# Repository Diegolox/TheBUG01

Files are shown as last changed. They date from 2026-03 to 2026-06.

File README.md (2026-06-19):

# TheBUG01 ⚡

## 🇬🇧 Project Description

<p align="justify">
This project is a custom <strong>all-in-one PCB</strong> for a <strong>two-wheel differential drive robot</strong>, designed to be <strong>plug-and-play</strong> and easy to integrate into new robotics prototypes. The board brings together the key building blocks needed for motion control and autonomous navigation, so you can focus on software and algorithms instead of wiring and power integration.
</p>

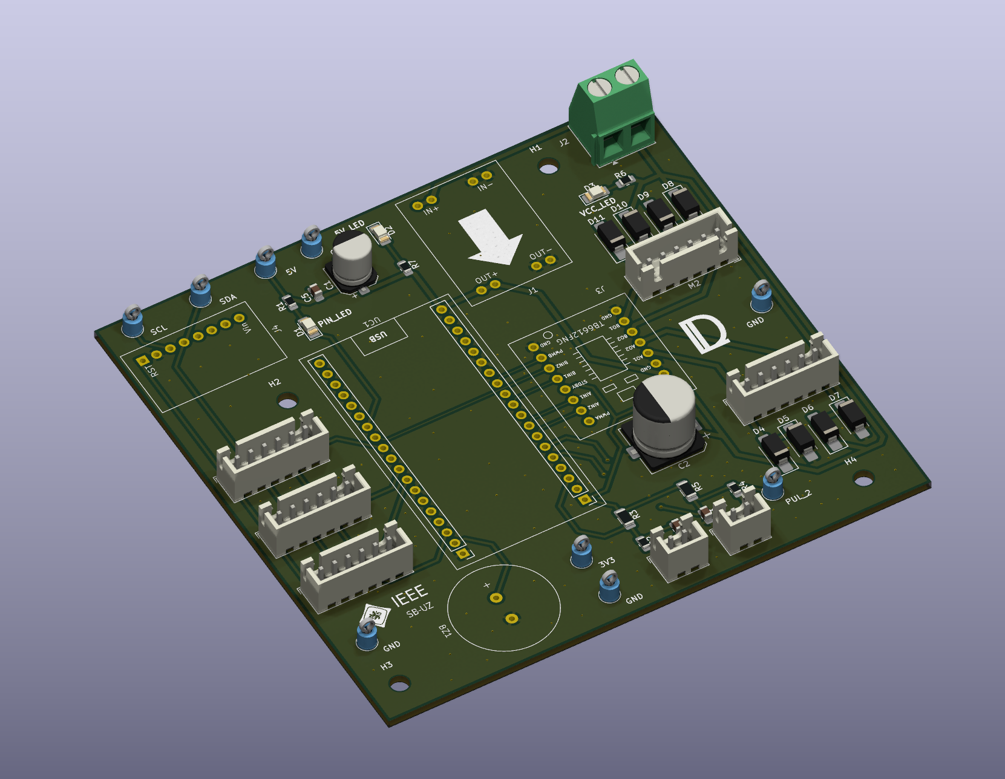
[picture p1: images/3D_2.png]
Vista 3D


### Key Features

* **2-wheel robot control PCB** with integrated peripherals for rapid development.
* **IMU (Inertial Measurement Unit)** for orientation and motion sensing.
* **3× TOF400 laser distance sensors** connected via **I²C**, enabling obstacle detection and basic autonomous navigation.
* **TB6612FNG dual motor driver** for controlling the DC motors efficiently (PWM + direction control).
* **Motor protection circuitry** to handle cases where motors behave like generators (back-EMF / regenerative effects), improving robustness and protecting the power stage.
* **Push buttons** with **RC filtering** and **external pull-up**, providing stable, noise-resistant digital inputs.
* **Test LEDs** for quick debugging and status indication during bring-up.
* **Integrated DC-DC converter** to step down from the **battery voltage** to the robot’s required internal rail(s), simplifying power distribution and improving overall reliability.

### PCB Layout
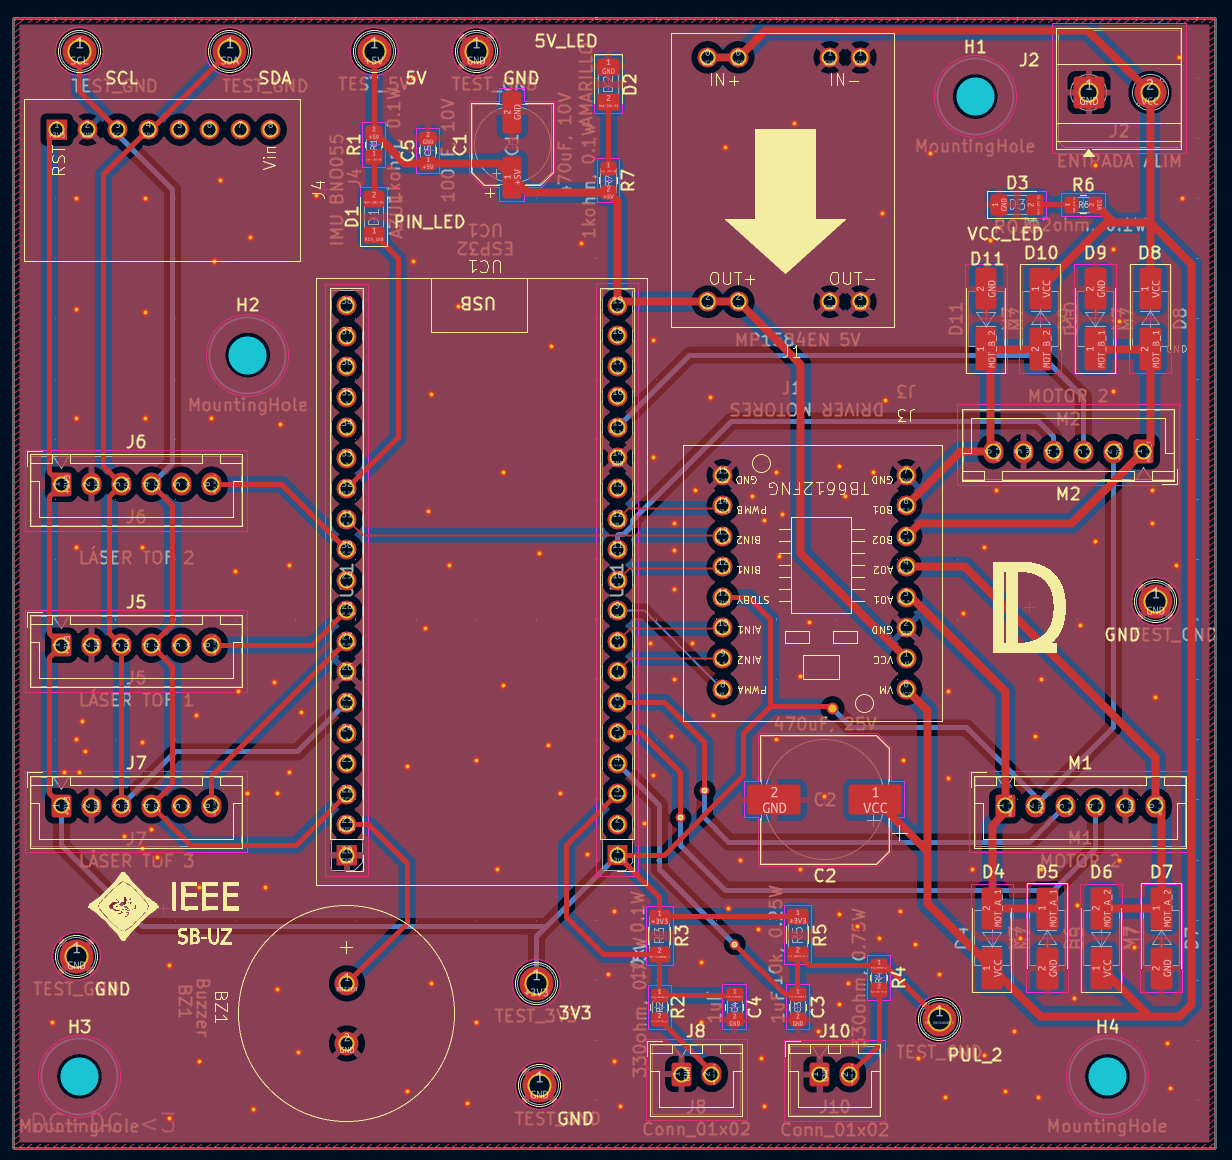
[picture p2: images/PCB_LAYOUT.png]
PCB Layout


### Schematic
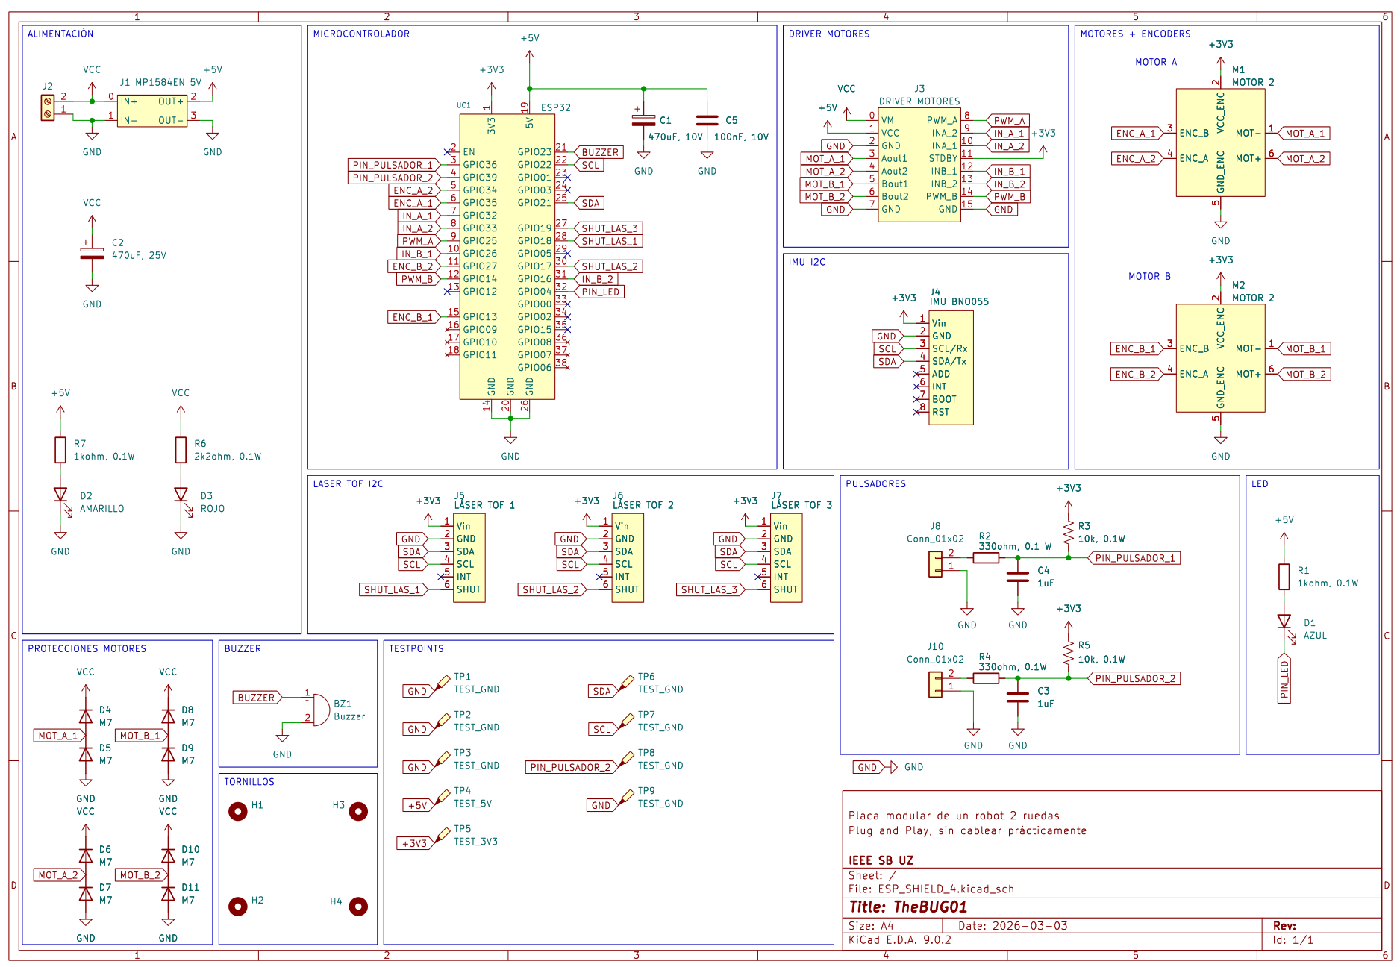
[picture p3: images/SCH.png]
Esquemático


### Goal

<p align="justify">
The goal of this PCB is to provide a compact robotics platform with <strong>everything integrated</strong>: power regulation, sensing, motor driving, and basic user I/O. With this hardware, you can quickly implement and iterate on:
</p>

* Wheel speed and position control loops
* Differential drive kinematics
* Sensor-based navigation using the TOF lasers
* Autonomous behaviors (obstacle avoidance, wall following, basic SLAM-ready sensing layout)

---

## 🇪🇸 Descripción del proyecto

<p align="justify">
Este proyecto es una <strong>PCB todo-en-uno</strong> para un <strong>robot diferencial de dos ruedas</strong>, pensada para ser <strong>plug-and-play</strong> y facilitar el desarrollo rápido de prototipos. La placa integra los bloques principales necesarios para control de movimiento y navegación autónoma, evitando cableado extra y problemas de integración de potencia.
</p>

### Características principales

* **PCB de control para robot de 2 ruedas** con periféricos integrados para desarrollo rápido.
* **IMU (Unidad de Medición Inercial)** para estimar orientación y movimiento.
* **3× sensores láser de distancia TOF400** por **I²C**, para detección de obstáculos y navegación básica.
* **Driver dual TB6612FNG** para el control eficiente de motores DC (PWM + dirección).
* **Circuitería de protección para motores** cuando actúan como generadores (back-EMF / regeneración), aumentando la robustez y protegiendo la etapa de potencia.
* **Pulsadores** con **filtro RC** y **pull-up externa**, para entradas digitales estables y resistentes al ruido.
* **LEDs de testeo** para depuración rápida y verificación del estado durante el bring-up.
* **Convertidor DC-DC integrado** para bajar la **tensión de baterías** a las líneas internas del robot, simplificando la distribución de potencia.

### Objetivo

<p align="justify">
El objetivo es ofrecer una plataforma compacta con <strong>todo integrado</strong>: regulación de potencia, sensórica, driver de motores y E/S básica. Con este hardware se pueden implementar de forma rápida:
</p>

* Control de velocidad/posición de ruedas
* Cinemática diferencial
* Navegación basada en sensores TOF
* Comportamientos autónomos (evitación de obstáculos, seguimiento de pared, base para SLAM)

---

* **Status:** In development
* **In collaboration with Carlos Rios Ferrer**

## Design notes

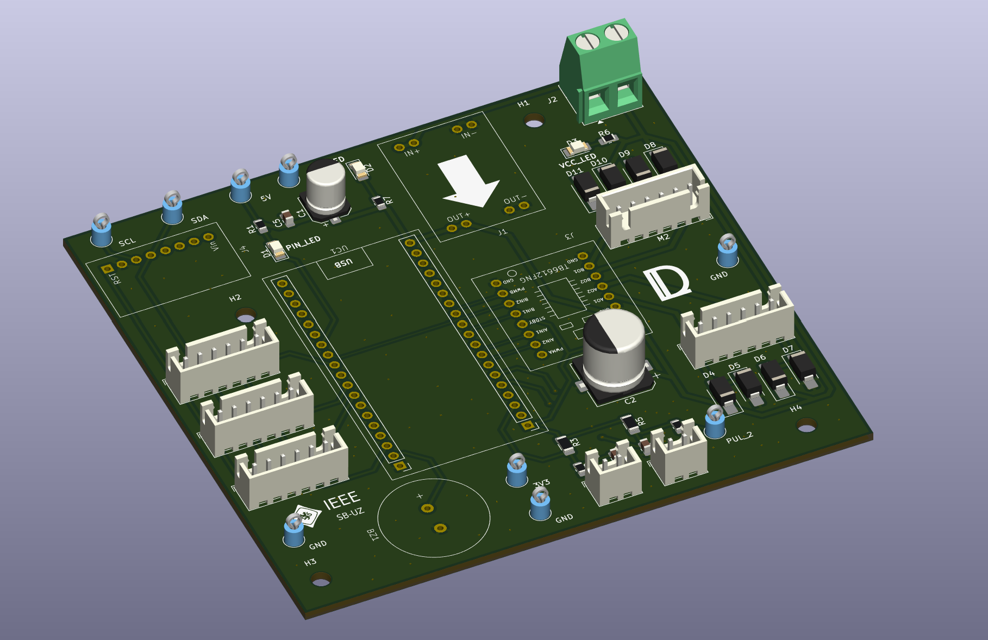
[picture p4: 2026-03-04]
images/3D.png

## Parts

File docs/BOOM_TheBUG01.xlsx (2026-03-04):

Reference | Qty | Value | DNP | Footprint
BZ1 | 1 | Buzzer |  | TOOLS_DIEGO:BUZZER
C1 | 1 | 470uF, 10V |  | Capacitor_SMD:CP_Elec_6.3x7.7
C2 | 1 | 470uF, 25V |  | Capacitor_SMD:CP_Elec_10x10.5
C3,C4 | 2 | 1uF |  | Capacitor_SMD:C_0805_2012Metric_Pad1.18x1.45mm_HandSolder
C5 | 1 | 100nF, 10V |  | Capacitor_SMD:C_0805_2012Metric_Pad1.18x1.45mm_HandSolder
D1 | 1 | AZUL |  | LED_SMD:LED_1206_3216Metric_Pad1.42x1.75mm_HandSolder
D2 | 1 | AMARILLO |  | LED_SMD:LED_1206_3216Metric_Pad1.42x1.75mm_HandSolder
D3 | 1 | ROJO |  | LED_SMD:LED_1206_3216Metric_Pad1.42x1.75mm_HandSolder
D4,D5,D6,D7,D8,D9,D10,D11 | 8 | M7 |  | Diode_SMD:D_SMA_Handsoldering
H1,H2,H3,H4 | 4 | MountingHole |  | MountingHole:MountingHole_3.2mm_M3
J1 | 1 | MP1584EN 5V |  | TOOLS_DIEGO:MP1584
J2 | 1 | ENTRADA ALIM |  | TerminalBlock_Phoenix:TerminalBlock_Phoenix_MKDS-1,5-2-5.08_1x02_P5.08mm_Horizontal
J3 | 1 | DRIVER MOTORES |  | TOOLS_DIEGO:TB6612FNG
J4 | 1 | IMU BNO055 |  | TOOLS_DIEGO:BNO055
J5 | 1 | LÃ SER TOF 1 |  | Connector_JST:JST_XH_B6B-XH-A_1x06_P2.50mm_Vertical
J6 | 1 | LÃ SER TOF 2 |  | Connector_JST:JST_XH_B6B-XH-A_1x06_P2.50mm_Vertical
J7 | 1 | LÃ SER TOF 3 |  | Connector_JST:JST_XH_B6B-XH-A_1x06_P2.50mm_Vertical
J8,J10 | 2 | Conn_01x02 |  | Connector_JST:JST_XH_B2B-XH-A_1x02_P2.50mm_Vertical
M1,M2 | 2 | MOTOR 2 |  | Connector_JST:JST_XH_B6B-XH-A_1x06_P2.50mm_Vertical
R1,R7 | 2 | 1kohm, 0.1W |  | Resistor_SMD:R_0805_2012Metric_Pad1.20x1.40mm_HandSolder
R2,R4 | 2 | 330ohm, 0.75W |  | Resistor_SMD:R_0805_2012Metric_Pad1.20x1.40mm_HandSolder
R3 | 1 | 10k, 0.1W |  | Resistor_SMD:R_1206_3216Metric_Pad1.30x1.75mm_HandSolder
R5 | 1 | 10k, 0.25W |  | Resistor_SMD:R_1206_3216Metric_Pad1.30x1.75mm_HandSolder
R6 | 1 | 2k2ohm, 0.1W |  | Resistor_SMD:R_0805_2012Metric_Pad1.20x1.40mm_HandSolder
TP1,TP2,TP3,TP6,TP7,TP8,TP9 | 7 | TEST_GND |  | TestPoint:TestPoint_Keystone_5005-5009_Compact
TP4 | 1 | TEST_5V |  | TestPoint:TestPoint_Keystone_5005-5009_Compact
TP5 | 1 | TEST_3V3 |  | TestPoint:TestPoint_Keystone_5005-5009_Compact
UC1 | 1 | ESP32 |  | ESP32_TOOLS_DIEGO:ESP32_WROOM32_SHIELD_V01

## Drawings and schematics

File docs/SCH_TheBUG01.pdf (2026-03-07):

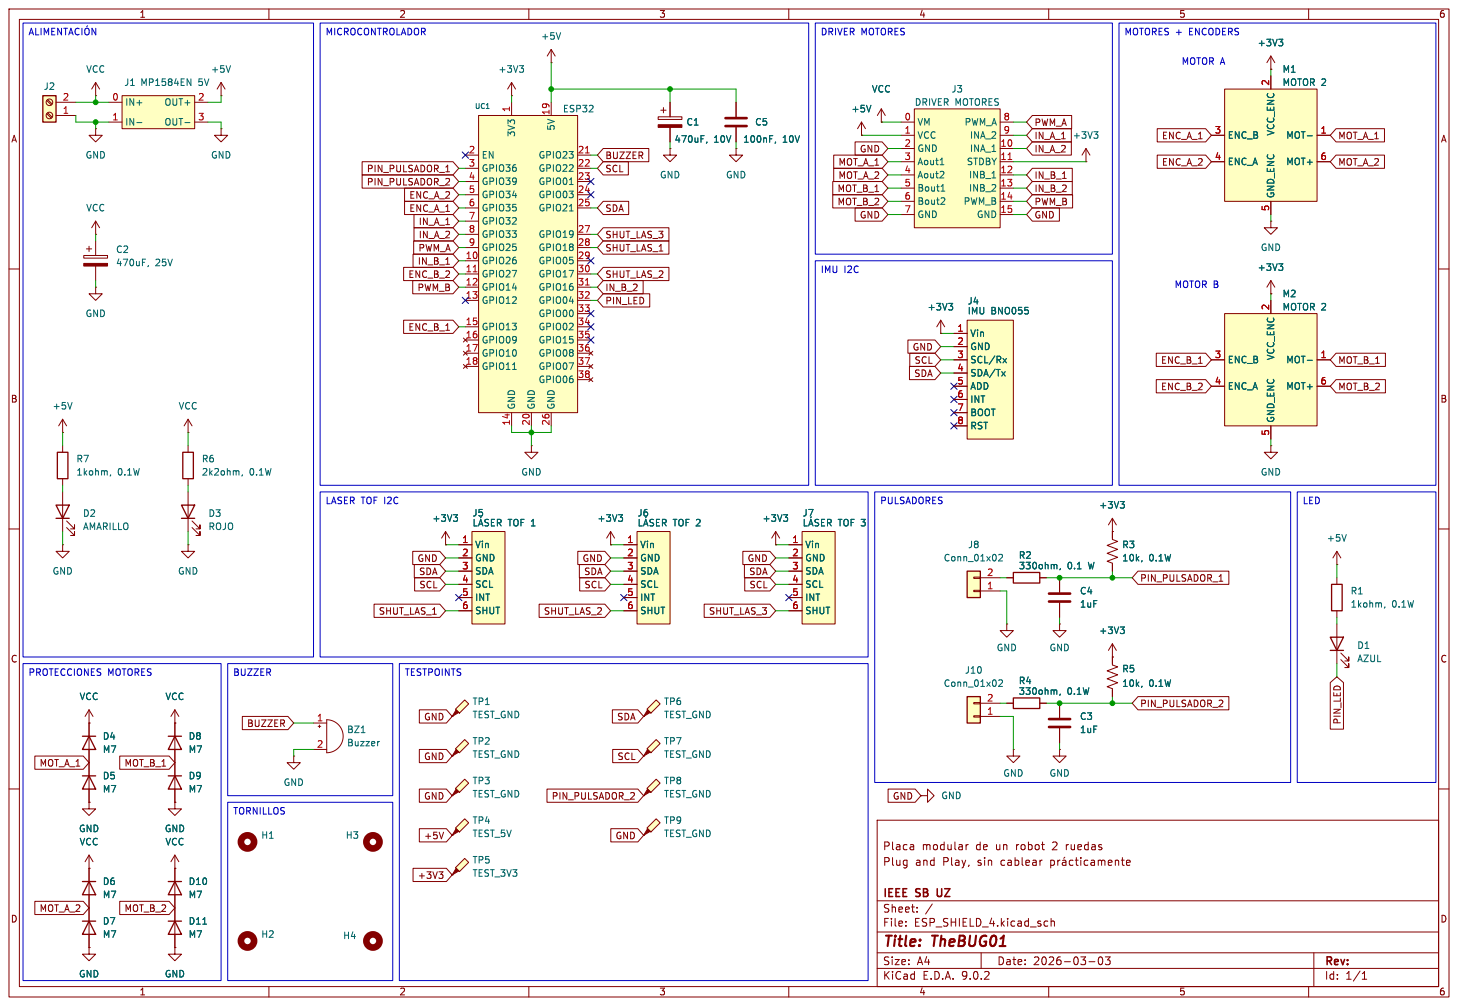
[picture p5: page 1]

5 MOT- 1 MOT+ 6 M2 MOTOR 2 GND

þÿLÁSER TOF 3 Vin 1 GND 2 SDA 3 SCL 4
Vin 1 GND 2 SDA 3 SCL 4

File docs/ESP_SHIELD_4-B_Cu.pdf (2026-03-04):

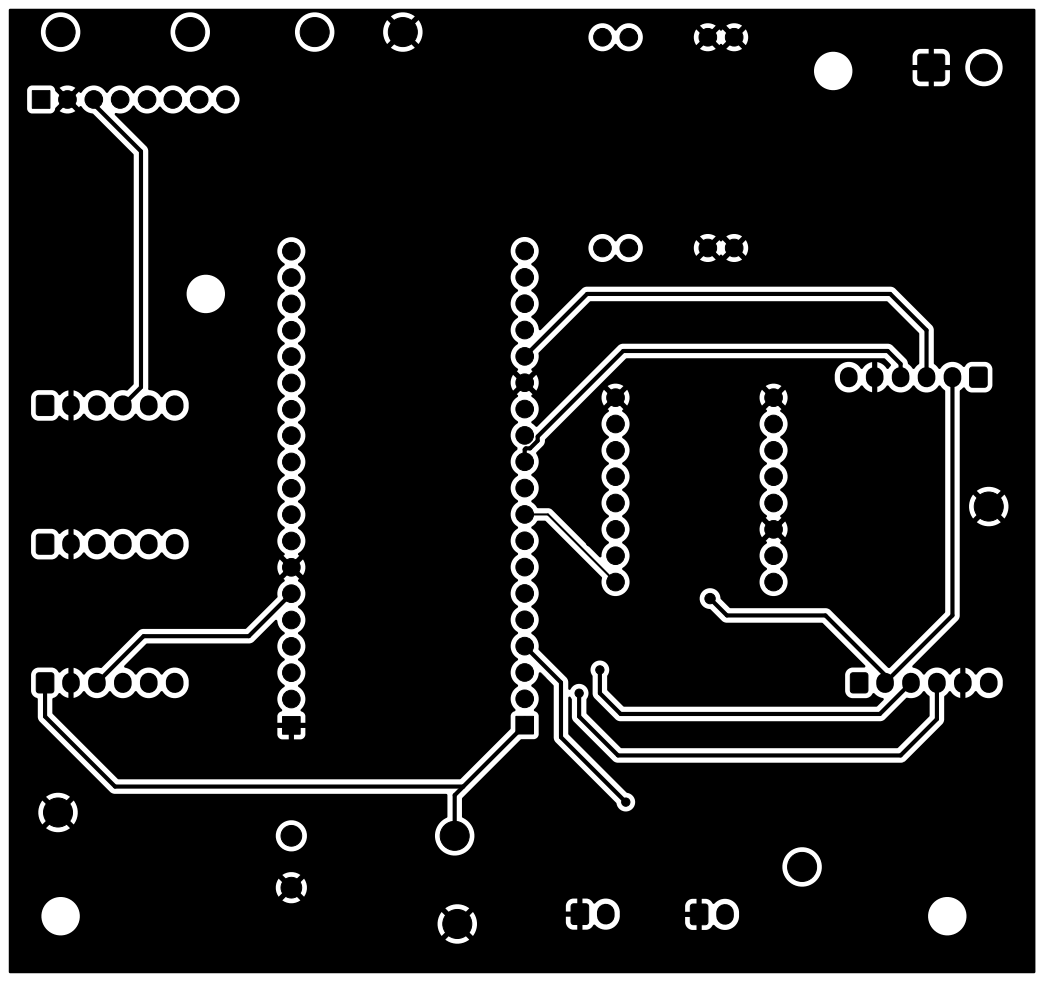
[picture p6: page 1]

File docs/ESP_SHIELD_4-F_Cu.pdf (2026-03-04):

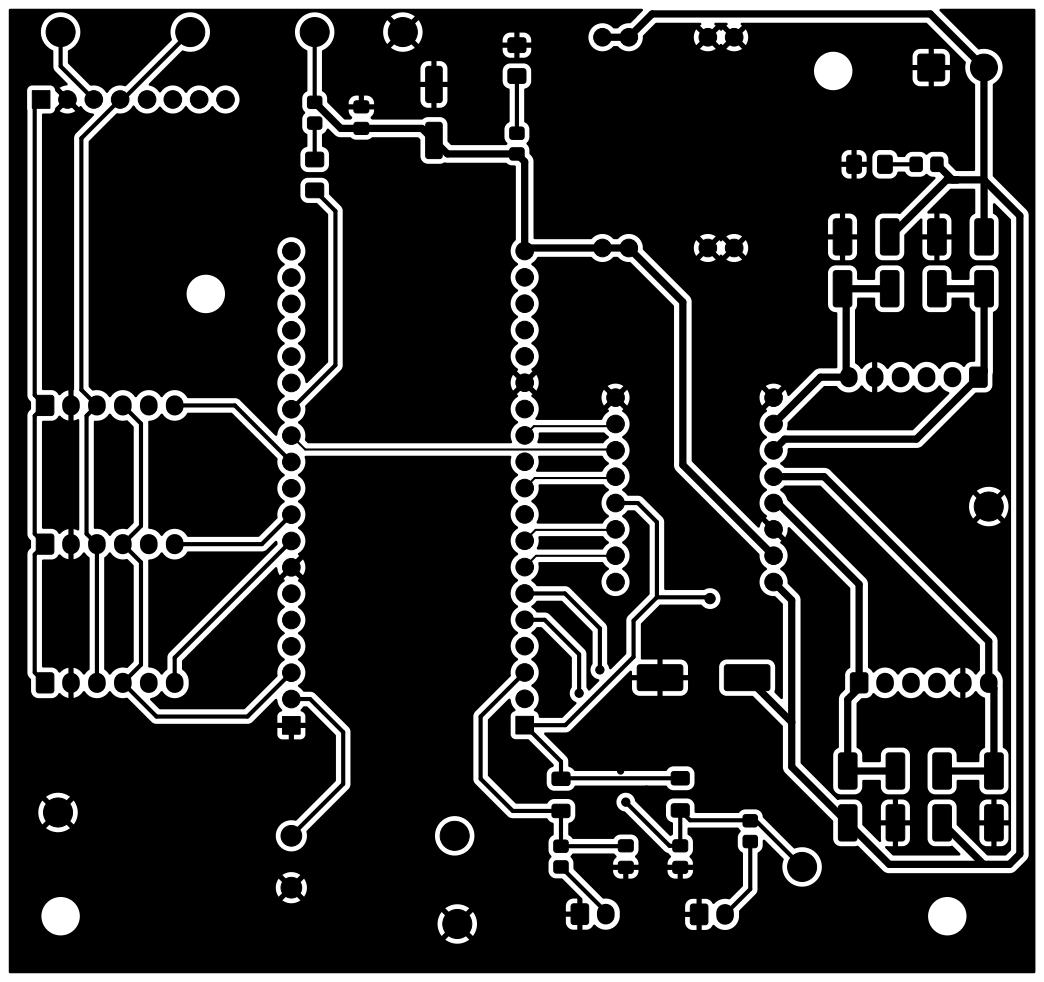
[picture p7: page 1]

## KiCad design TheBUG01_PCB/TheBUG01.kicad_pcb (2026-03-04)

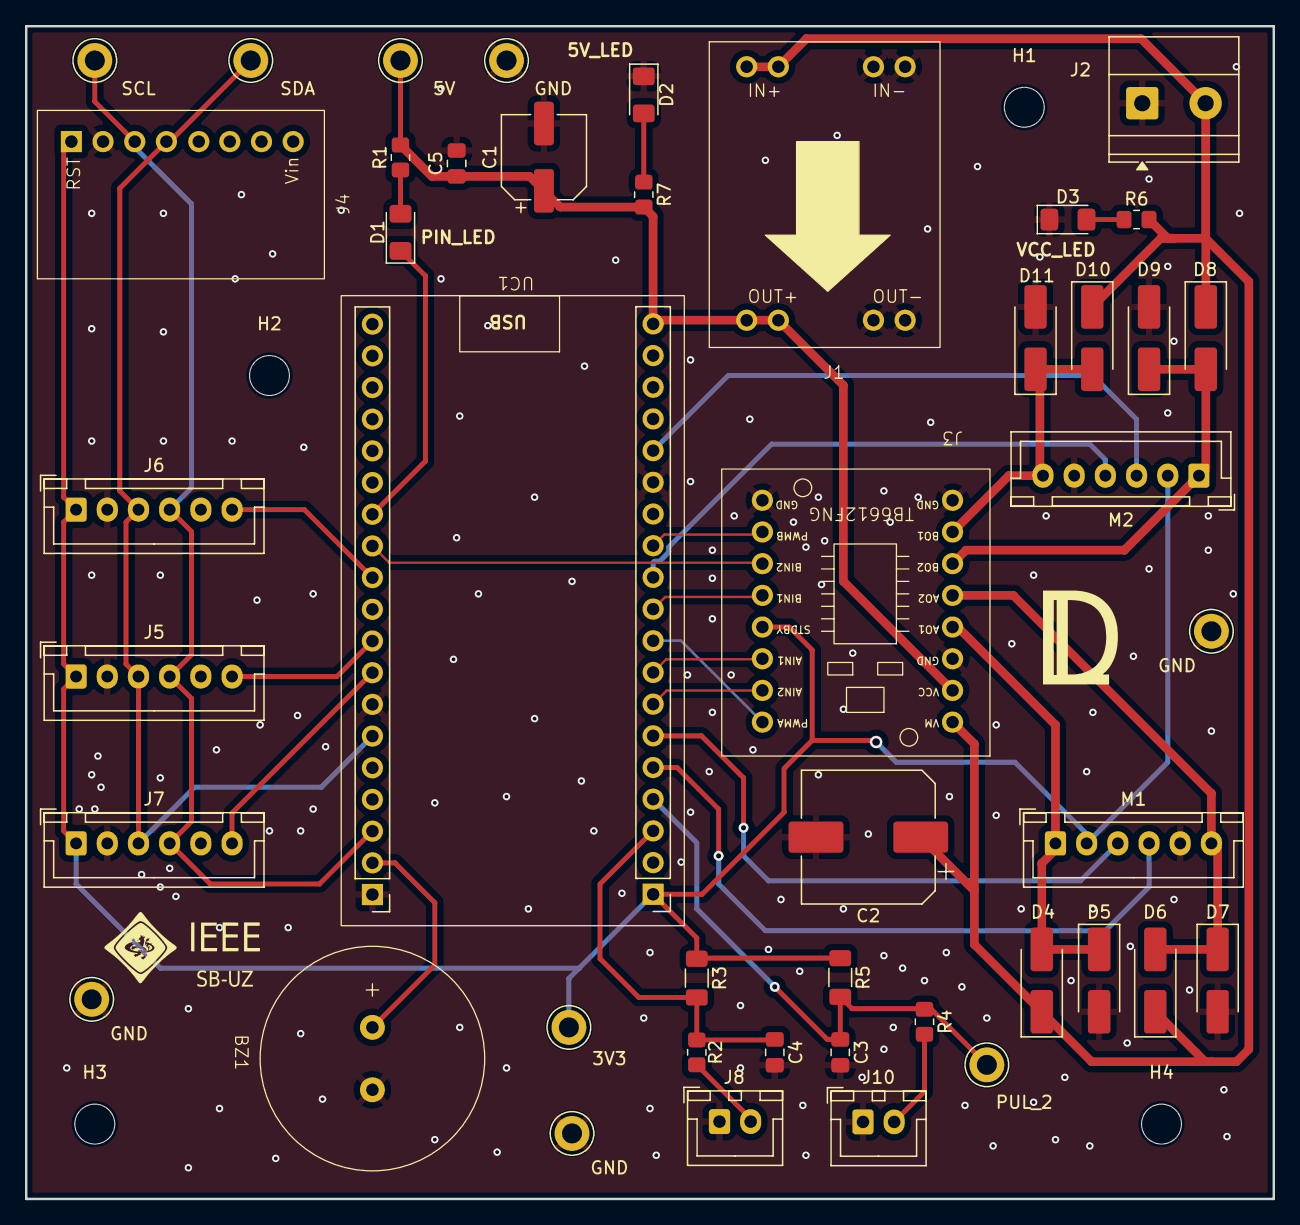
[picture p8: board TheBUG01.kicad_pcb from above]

Board: 2 copper layers, 100.0 x 94.0 mm, 49 parts (0 on the bottom side), 32 nets.

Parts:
3V3: TEST_3V3; TestPoint_Keystone_5005-5009_Compact
5V: TEST_5V; TestPoint_Keystone_5005-5009_Compact
BZ1: Buzzer; BUZZER
C1: 470uF, 10V; CP_Elec_6.3x7.7
C2: 470uF, 25V; CP_Elec_10x10.5
C3, C4: 1uF; C_0805_2012Metric_Pad1.18x1.45mm_HandSolder
C5: 100nF, 10V; C_0805_2012Metric_Pad1.18x1.45mm_HandSolder
D1: AZUL; LED_1206_3216Metric_Pad1.42x1.75mm_HandSolder
D2: AMARILLO; LED_1206_3216Metric_Pad1.42x1.75mm_HandSolder
D3: ROJO; LED_1206_3216Metric_Pad1.42x1.75mm_HandSolder
D4, D5, D6, D7, D8, D9, D10, D11: M7; D_SMA_Handsoldering
GND: TEST_GND; TestPoint_Keystone_5005-5009_Compact
GND#2, GND#3, GND#4: TEST_GND; TestPoint_Keystone_5005-5009_Compact
H1, H2, H3, H4: MountingHole; MountingHole_3.2mm_M3
J1: MP1584EN 5V; MP1584
J2: ENTRADA ALIM; TerminalBlock_Phoenix_MKDS-1,5-2-5.08_1x02_P5.08mm_Horizont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
J3: DRIVER MOTORES; TB6612FNG
J4: IMU BNO055; BNO055
J5: LÁSER TOF 1; JST_XH_B6B-XH-A_1x06_P2.50mm_Vertical
J6: LÁSER TOF 2; JST_XH_B6B-XH-A_1x06_P2.50mm_Vertical
J7: LÁSER TOF 3; JST_XH_B6B-XH-A_1x06_P2.50mm_Vertical
J8, J10: Conn_01x02; JST_XH_B2B-XH-A_1x02_P2.50mm_Vertical
M1, M2: MOTOR 2; JST_XH_B6B-XH-A_1x06_P2.50mm_Vertical
PUL_2: TEST_GND; TestPoint_Keystone_5005-5009_Compact
R1, R7: 1kohm, 0.1W; R_0805_2012Metric_Pad1.20x1.40mm_HandSolder
R2, R4: 330ohm, 0.75W; R_0805_2012Metric_Pad1.20x1.40mm_HandSolder
R3: 10k, 0.1W; R_1206_3216Metric_Pad1.30x1.75mm_HandSolder
R5: 10k, 0.25W; R_1206_3216Metric_Pad1.30x1.75mm_HandSolder
R6: 2k2ohm, 0.1W; R_0805_2012Metric_Pad1.20x1.40mm_HandSolder
SCL: TEST_GND; TestPoint_Keystone_5005-5009_Compact
SDA: TEST_GND; TestPoint_Keystone_5005-5009_Compact
UC1: ESP32; ESP32_WROOM32_SHIELD_V01

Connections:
+3V3: 3V3.1, J3.11 (STDBY), J4.1 (Vin), J5.1 (Vin), J6.1 (Vin), J7.1 (Vin), M1.2 (VCC_ENC), M2.2 (VCC_ENC), R3.1, R5.1, UC1.1 (3V3)
+5V: 5V.1, C1.1, C5.1, J1.2 (OUT+), J3.1 (VCC), R1.2, R7.2, UC1.19 (5V)
BUZZER: BZ1.1 (+), UC1.21 (GPIO23)
ENC_A_1: M1.3 (ENC_B), UC1.6 (GPIO35)
ENC_A_2: M1.4 (ENC_A), UC1.5 (GPIO34)
ENC_B_1: M2.3 (ENC_B), UC1.15 (GPIO13)
ENC_B_2: M2.4 (ENC_A), UC1.11 (GPIO27)
GND: BZ1.2 (-), C1.2, C2.2, C3.2, C4.2, C5.2, D2.1 (K), D3.1 (K), D5.2 (A), D7.2 (A), D9.2 (A), D11.2 (A), GND.1, GND#2.1, GND#3.1, GND#4.1, J1.1 (IN-), J1.3 (OUT-), J2.1, J3.2 (GND), J3.7 (GND), J3.15 (GND), J4.2 (GND), J5.2 (GND), J6.2 (GND), J7.2 (GND), J8.1, J10.1, M1.5 (GND_ENC), M2.5 (GND_ENC), UC1.14 (GND), UC1.20 (GND), UC1.26 (GND)
IN_A_1: J3.9 (INA_2), UC1.7 (GPIO32)
IN_A_2: J3.10 (INA_1), UC1.8 (GPIO33)
IN_B_1: J3.12 (INB_1), UC1.10 (GPIO26)
IN_B_2: J3.13 (INB_2), UC1.31 (GPIO16)
MOT_A_1: D4.2 (A), D5.1 (K), J3.3 (Aout1), M1.1 (MOT-)
MOT_A_2: D6.2 (A), D7.1 (K), J3.4 (Aout2), M1.6 (MOT+)
MOT_B_1: D8.2 (A), D9.1 (K), J3.5 (Bout1), M2.1 (MOT-)
MOT_B_2: D10.2 (A), D11.1 (K), J3.6 (Bout2), M2.6 (MOT+)
unnamed: D1.2 (A), R1.1
unnamed: D2.2 (A), R7.1
unnamed: D3.2 (A), R6.1
unnamed: J8.2, R2.2
unnamed: J10.2, R4.2
PIN_LED: D1.1 (K), UC1.32 (GPIO04)
PIN_PULSADOR_1: C4.1, R2.1, R3.2, UC1.3 (GPIO36)
PIN_PULSADOR_2: C3.1, PUL_2.1, R4.1, R5.2, UC1.4 (GPIO39)
PWM_A: J3.8 (PWM_A), UC1.9 (GPIO25)
PWM_B: J3.14 (PWM_B), UC1.12 (GPIO14)
SCL: J4.3 (SCL/Rx), J5.4 (SCL), J6.4 (SCL), J7.4 (SCL), SCL.1, UC1.22 (GPIO22)
SDA: J4.4 (SDA/Tx), J5.3 (SDA), J6.3 (SDA), J7.3 (SDA), SDA.1, UC1.25 (GPIO21)
SHUT_LAS_1: J5.6 (SHUT), UC1.28 (GPIO18)
SHUT_LAS_2: J6.6 (SHUT), UC1.30 (GPIO17)
SHUT_LAS_3: J7.6 (SHUT), UC1.27 (GPIO19)
VCC: C2.1, D4.1 (K), D6.1 (K), D8.1 (K), D10.1 (K), J1.0 (IN+), J2.2, J3.0 (VM), R6.2
